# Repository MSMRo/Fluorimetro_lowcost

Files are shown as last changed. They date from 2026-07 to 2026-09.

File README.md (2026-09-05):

# Fluorímetro Low Cost

Proyecto de desarrollo de un fluorímetro de bajo costo basado en Arduino. Este proyecto integra circuitos de transmisión, recepción y diseño 3D para crear un sistema completo de medición de fluorescencia.

## 📋 Descripción General

Un fluorímetro es un instrumento que mide la fluorescencia de sustancias. Este proyecto implementa una solución accesible utilizando:
- **Plataforma de control**: Arduino Mega
- **Sensor espectral**: AS7341 (multiespectrométrico)
- **Excitación**: LED controlado con DAC Delta-Sigma
- **Visualización**: Pantalla OLED Nokia 5110

## 📁 Estructura del Proyecto

```
Fluorimetro_lowcost/
├── 1_Circuito/              # Diseños de circuitos
│   ├── 1_Transmisor/        # Circuito transmisor (LED de excitación)
│   │   └── 1_TESTS/         # Pruebas y códigos
│   │       ├── 1_CORRIENTE_DELTA_SIGMA/  # Pruebas DAC Delta-Sigma
│   │       ├── 2_DAC_LED_UNO_R4/         # Pruebas para UNO R4
│   │       └── 3_TEST_KICAD/             # Diseño del shield en KiCAD
│   └── 2_Receptor/          # Circuito receptor (sensor AS7341)
│       └── 1_TEST_AS7341/   # Códigos y pruebas del sensor
├── 3_Diseño3D/              # Modelos 3D (FreeCAD)
│   ├── 1_CASE_MEGA/         # Case para Arduino Mega v1
│   └── 2_CASE_MEGA_CUBO/    # Case con cubo integrado v2
└── README.md
```

## 🔧 Circuitos

### 1. Transmisor (1_Circuito/1_Transmisor/)

Responsable de generar la luz de excitación para estimular la fluorescencia de la muestra.

**Características principales:**
- Controlador de LED con DAC Delta-Sigma para modulación de intensidad
- Múltiples versiones testeadas:
  - **Delta-Sigma para Arduino Mega**: Conversión analógica de alta resolución
  - **DAC LED UNO R4**: Variante para Arduino UNO R4
  - **Shield KiCAD**: Diseño de PCB personalizado con biblioteca 3D

**Pruebas incluidas:**
- `dac_delta_sigma_MEGA_R3_v1.ino`: Firmware para Mega
- `dac_delta_sigma_UNO_R3_v1.ino`: Firmware para UNO
- Simulaciones en SPICE para validación

### 2. Receptor (1_Circuito/2_Receptor/)

Captura el espectro de luz emitido por la muestra fluorescente.

**Sensor AS7341 (ams OSRAM):**
- **10 canales de medición**:
  - 8 canales visibles (F1-F8): 415 nm a 680 nm
  - 1 canal NIR (infrarrojo cercano): 910 nm
  - 1 canal Clear (luz blanca sin filtro)
- **Comunicación**: I2C (SDA/SCL)
- **Características**:
  - Conversores ADC independientes para cada canal
  - Ganancia ajustable (hasta 512x+)
  - Tiempo de integración configurable
  - Ideal para detectar señales tenues sin saturación

**Códigos de prueba:**
- `firmware2.ino`: Firmware principal funcional (control de LED + lectura de máximos)
- `long_onda_oled.ino`: Visualización en pantalla OLED Nokia
- `maximo_4long_onda.ino`: Muestra los 4 canales con máxima intensidad
- Librería: **Adafruit AS7341** (IDE Arduino)

**Visualización:**
- Pantalla OLED Nokia 5110 con comunicación SPI
- Display de 84x48 píxeles con limitación visual (se muestran 4 máximos canales)

## 🎨 Diseño 3D

Modelos CAD para encapsulamiento y estructura mecánica del dispositivo.

### CASE_MEGA (1_CASE_MEGA/)
- **Prototipo v1** del case para Arduino Mega
- Adaptación de diseño de terceros para incluir compartimento de cuveta
- Software: FreeCAD v1.1.1
- Basado en: [Arduino Mega 2560 Case](https://www.printables.com/model/523194-arduino-mega-2560-case/files)

### CASE_MEGA_CUBO (2_CASE_MEGA_CUBO/)
- **Prototipo v2** con integración del cubo de excitación
- Combina case del Arduino Mega + estructura para fluoróforo
- Diseño consolidado en un solo componente

## 🛠️ Herramientas y Tecnologías

| Componente | Herramienta/Tecnología |
|---|---|
| Placa de control | Arduino Mega 2560 |
| Sensor | AS7341 (ams OSRAM) |
| Prototipado electrónico | KiCAD |
| Modelado 3D | FreeCAD v1.1.1 |
| Simulación de circuitos | SPICE |
| Programación | Arduino IDE, C/C++ |

## 📚 Bibliotecas Requeridas

- **Adafruit AS7341**: Control del sensor espectral
- **Adafruit GFX**: Gráficos para pantallas
- **Adafruit PCD8544**: Control de pantalla Nokia 5110
- **Wire**: Protocolo I2C
- **SPI**: Protocolo SPI

## 🚀 Estado del Proyecto

- ✅ Sensor AS7341 funcionando correctamente
- ✅ Control de LED con DAC Delta-Sigma
- ✅ Visualización en OLED Nokia
- ✅ Diseños 3D de prototipos
- 🔄 Optimización y validación del sistema completo

## 📝 Notas

- El firmware2 es la versión principal estable
- Se han testeado múltiples configuraciones de hardware
- Los diseños 3D están listos para impresión 3D
- Documentación con imágenes disponible en cada subdirectorio

---

*Proyecto en desarrollo - Low Cost Fluorimeter*

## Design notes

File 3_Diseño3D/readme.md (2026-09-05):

## Protipo de case para arduino mega 1
### Nombre: CASE_MEGA
Se uso un ```stl``` de un arduino mega y luego se adaptó para tener la capacidad de adicionar la parte del cuveta para colocar el fluoroforo.

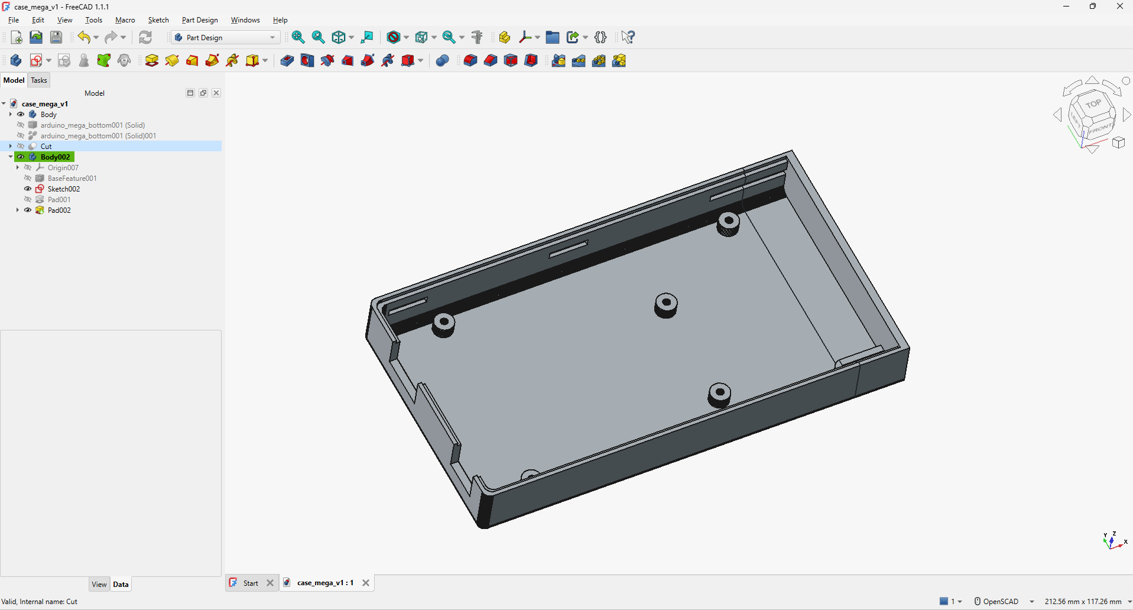
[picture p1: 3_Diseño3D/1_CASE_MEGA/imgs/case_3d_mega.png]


EL diseño se adaptó de este proyecto [LINK_PROYECTO](https://www.printables.com/model/523194-arduino-mega-2560-case/files)

El software usado fue:
- Freecad v1.1.1

## Protipo de case para arduino mega 2
### Nombre: CASE_MEGA_CUBO
Se realizó otro diseño 3D del prototipo, en esta ocasión se juntaron el case del arduino mega y el cubo para realizar la excitación del fluoroforo.
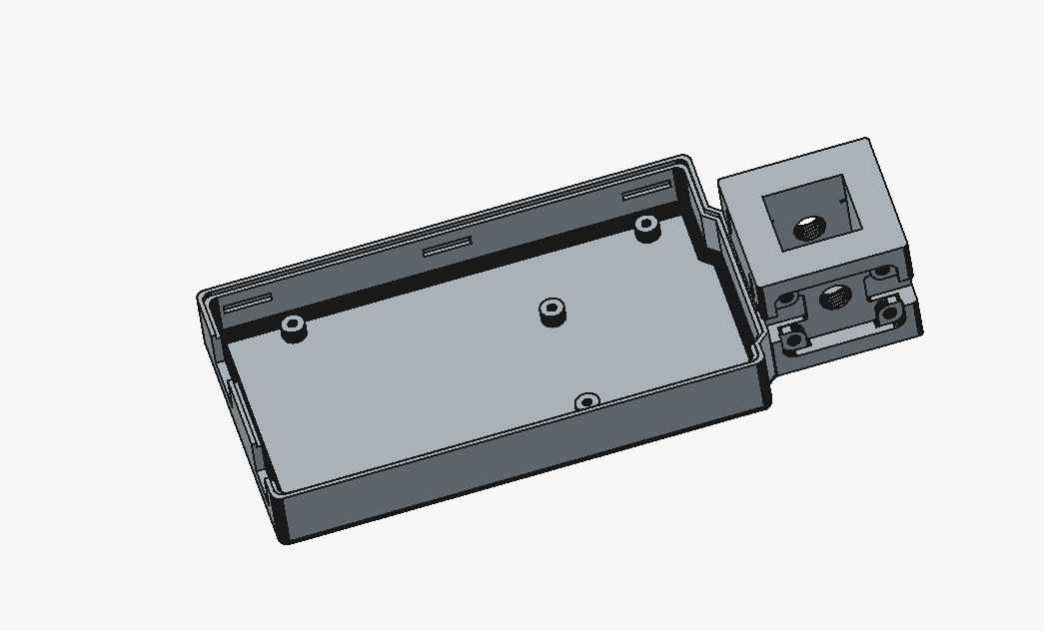
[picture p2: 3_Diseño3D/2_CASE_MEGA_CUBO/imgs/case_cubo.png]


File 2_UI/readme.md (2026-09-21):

# Arquitectura de software de `UI_Miguel`

Esta sección describe la arquitectura del contenido de [`UI_Miguel/`](UI_Miguel/) con el modelo C4. La ruta principal es la demostración con Arduino Mega 2560 y AS7341; la integración IO Rodeo con PyBadge y TSL2591 se conserva como una ruta histórica compatible.

## Nivel 1: contexto del sistema

El sistema permite operar el fluorímetro, observar las lecturas espectrales y conservar resultados experimentales. La persona operadora interactúa con la GUI desde un computador; el hardware realiza la adquisición y aplica los parámetros recibidos.

```mermaid
C4Context
	title Contexto del sistema: UI_Miguel

	Person(operator, "Operador/a", "Configura la adquisición, observa las lecturas y registra experimentos")
	System(fluorimeter, "Sistema de software del fluorímetro", "Controla la adquisición, procesa las mediciones y guarda la evidencia experimental")
	System_Ext(mega, "Arduino Mega + AS7341", "Adquiere diez canales y controla el LED por PWM")
	System_Ext(nokia, "Pantalla Nokia 5110", "Muestra el estado y los canales medidos")
	System_Ext(io_rodeo, "IO Rodeo + PyBadge", "Ruta histórica con TSL2591 y firmware adaptado")
	System_Ext(filesystem, "Sistema de archivos", "Almacena sesiones JSON y telemetría CSV")

	Rel(operator, fluorimeter, "Opera mediante")
	Rel(fluorimeter, mega, "Configura y recibe telemetría por USB serial")
	Rel(mega, nokia, "Actualiza la pantalla local")
	Rel(fluorimeter, io_rodeo, "Puede operar la ruta histórica por USB CDC")
	Rel(fluorimeter, filesystem, "Guarda sesiones y exportaciones")
```

## Nivel 2: contenedores

En C4, los contenedores son unidades desplegables o ejecutables. En la ruta Mega, la aplicación Python se ejecuta en el computador y el firmware C++ se carga en el microcontrolador.

```mermaid
C4Container
	title Contenedores: GUI Mega y firmware

	Person(operator, "Operador/a", "Usuario del instrumento")
	System_Boundary(system, "Sistema del fluorímetro") {
		Container(gui, "GUI de escritorio", "Python + PyQt", "Interfaz, adquisición, análisis, experimentos, gráficos y exportaciones")
		ContainerDb(sessions, "Sesiones y registros", "JSON + CSV", "Experimentos, telemetría y resultados recuperables")
		Container(serial, "Enlace USB serial", "JSON Lines, 115200 baudios", "Transporte de comandos y telemetría")
		Container(firmware, "Firmware Mega", "C++ / Arduino", "Lectura AS7341, pantalla Nokia, configuración y PWM D11")
	}
	System_Ext(sensor, "AS7341", "Sensor multicanal")
	System_Ext(display, "Nokia 5110", "Pantalla local")

	Rel(operator, gui, "Configura y observa")
	Rel(gui, serial, "Envía comandos y recibe líneas JSON")
	Rel(serial, firmware, "Transporta el protocolo")
	Rel(firmware, sensor, "Lee F1-F8, NIR y Clear por I2C")
	Rel(firmware, display, "Renderiza dos páginas de cinco valores")
	Rel(gui, sessions, "Lee y escribe sesiones, CSV y resultados")
```

La ruta histórica utiliza los contenedores `IO_Rodeo_TSL2591_GUI/v1.0` y `Firmware/IO_Rodeo_PyBadge/v2.0_tsl2591_gui`. La GUI recibe por USB CDC los valores que el PyBadge usa para su pantalla y permite observarlos, graficarlos y exportarlos; no sustituye la adquisición del firmware.

## Nivel 3: componentes de la GUI Mega

Los componentes se corresponden con los módulos de [`Software/Arduino_Mega_AS7341_GUI/v1.0/desktop_gui/`](UI_Miguel/Software/Arduino_Mega_AS7341_GUI/v1.0/desktop_gui/).

```mermaid
C4Component
	title Componentes: GUI Arduino Mega + AS7341

	Container_Boundary(gui, "GUI de escritorio") {
		Component(window, "Ventana principal", "main_window.py", "Coordina controles, estado y vistas")
		Component(protocol, "Protocolo", "protocol.py", "Codifica comandos y valida mensajes JSON Lines")
		Component(client, "Cliente serial", "serial_client.py", "Gestiona el puerto USB y la comunicación")
		Component(acquisition, "Adquisición", "acquisition.py", "Recibe, valida y distribuye frames de medición")
		Component(plot, "Vista espectral", "spectral_plot.py", "Grafica F1-F8 y aplica escala fija o automática")
		Component(mirror, "Espejo Nokia", "display_mirror.py", "Representa el estado mostrado por la pantalla local")
		Component(experiments, "Experimentos", "experiments.py", "Gestiona blancos, señales, cocientes y calibración")
		Component(analysis, "Análisis y calidad", "fluorometry.py + results_quality.py", "Calcula intensidades, estadísticas, residuos y resultados")
		Component(storage, "Persistencia y exportación", "session_store.py + telemetry_writer.py + exporter.py", "Guarda JSON, CSV y sesiones recuperables")
	}
	Container_Ext(firmware, "Firmware Mega", "C++ / Arduino", "Telemetría y control del instrumento")

	Rel(window, acquisition, "Consume estado y mediciones")
	Rel(window, plot, "Actualiza la vista")
	Rel(window, mirror, "Actualiza el espejo")
	Rel(window, experiments, "Inicia y valida capturas")
	Rel(window, analysis, "Muestra resultados")
	Rel(protocol, client, "Define mensajes")
	Rel(client, firmware, "Envía comandos y recibe JSON Lines")
	Rel(client, acquisition, "Entrega telemetría")
	Rel(acquisition, storage, "Registra mediciones")
	Rel(experiments, analysis, "Entrega capturas y configuración")
	Rel(analysis, storage, "Persiste resultados y derivados")
```

## Nivel 4: código y contratos principales

El nivel de código se resume en los contratos que conectan los componentes. No se detallan todas las funciones internas para evitar convertir el README en una copia del código fuente.

| Elemento | Responsabilidad o contrato |
| --- | --- |
| `mega_as7341_multichannel.ino` + `firmware.cpp` | Inicializa AS7341 y Nokia, lee diez canales raw, aplica ganancia, integración y PWM de D11, y emite estado/telemetría JSON Lines. |
| `protocol.py` | Mantiene el formato de comandos como `set_gain`, `set_integration`, `set_pwm` y las respuestas del firmware. |
| `serial_client.py` | Abre el puerto USB a 115200 baudios y separa las líneas recibidas del dispositivo. |
| `acquisition.py` | Convierte la telemetría en frames de adquisición y conserva la información de saturación `OVFL`. |
| `experiments.py` | Modela capturas de blanco, señal, A/B, réplicas y compatibilidad de configuración. |
| `fluorometry.py` + `results_quality.py` | Calculan intensidades corregidas, cocientes, estadísticas, residuos y controles de calidad sin inventar datos ausentes. |
| `session_store.py` + `telemetry_writer.py` + `exporter.py` | Persisten la sesión en JSON, la telemetría en CSV y las tablas derivadas para análisis posterior. |

### Flujo de datos principal

1. El operador cambia ganancia, integración o PWM en la GUI.
2. `protocol.py` serializa el comando y `serial_client.py` lo envía al Mega.
3. El firmware configura el AS7341, adquiere F1-F8, NIR y Clear, actualiza la Nokia y devuelve JSON Lines.
4. `acquisition.py` valida el frame; la gráfica y el espejo muestran el estado actual.
5. `experiments.py` captura la medición bajo una configuración identificable.
6. `fluorometry.py` y `results_quality.py` calculan los derivados; la capa de persistencia guarda JSON y CSV.

### Límites de la arquitectura

- Las pruebas host del firmware y las pruebas Qt validan el contrato de software, pero no reemplazan la validación óptica con estándares y el montaje real.
- Las lecturas del AS7341 se conservan como cuentas ADC raw; `OVFL` representa saturación digital.
- La carpeta `reference_upstream` del firmware IO Rodeo es material de referencia y no forma parte del flujo principal de desarrollo.

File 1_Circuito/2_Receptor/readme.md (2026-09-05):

# RECEPTOR

A nivel del receptor estamos trabajando con el AS7341
El AS7341 es un sensor espectral multicanal de alta precisión desarrollado por ams OSRAM, ideal para aplicaciones de análisis de color y espectroscopia como tu fluorímetro:
* Canales de Medición: Cuenta con un total de 10 canales:
    * 8 canales visibles (F1 a F8) con filtros ópticos integrados de fábrica, que cubren desde el violeta hasta el rojo lejano (de $415\text{ nm}$ a $680\text{ nm}$).
    * 1 canal NIR (Infrarrojo Cercano) sintonizado a $910\text{ nm}$.
    * 1 canal Clear que mide la luz blanca total sin filtrar.

* Comunicación: Se conecta mediante el protocolo I2C, lo que facilita su integración directa con microcontroladores como el Arduino Mega utilizando solo dos cables de datos (SDA y SCL).
* Conversión Analógica-Digital (ADC): Incorpora conversores ADC independientes para procesar las lecturas de los fotodiodos de manera simultánea, entregando datos digitales de alta resolución directamente al microcontrolador.
* Ganancia y Tiempo de Integración Ajustables: Permite configurar parámetros de ganancia interna (hasta 512x o más) y tiempos de integración mediante software, lo cual es fundamental en fluorometría para detectar señales de luz extremadamente tenues sin saturar el sensor.


# Pruebas
La libreria para usar el AS7341 es ```Adafruit AS7341``` en el ide de arduino.

## 1_TEST_AS7341

### firmware2
Actualmente el firmware2 es el código funcional. Permite controlar el brillo del LED y la muestra de los maximos valores de los canales del sensor.


### long_onda_oled
Se desarrollo un código para mostrar los canales y su intensidad.

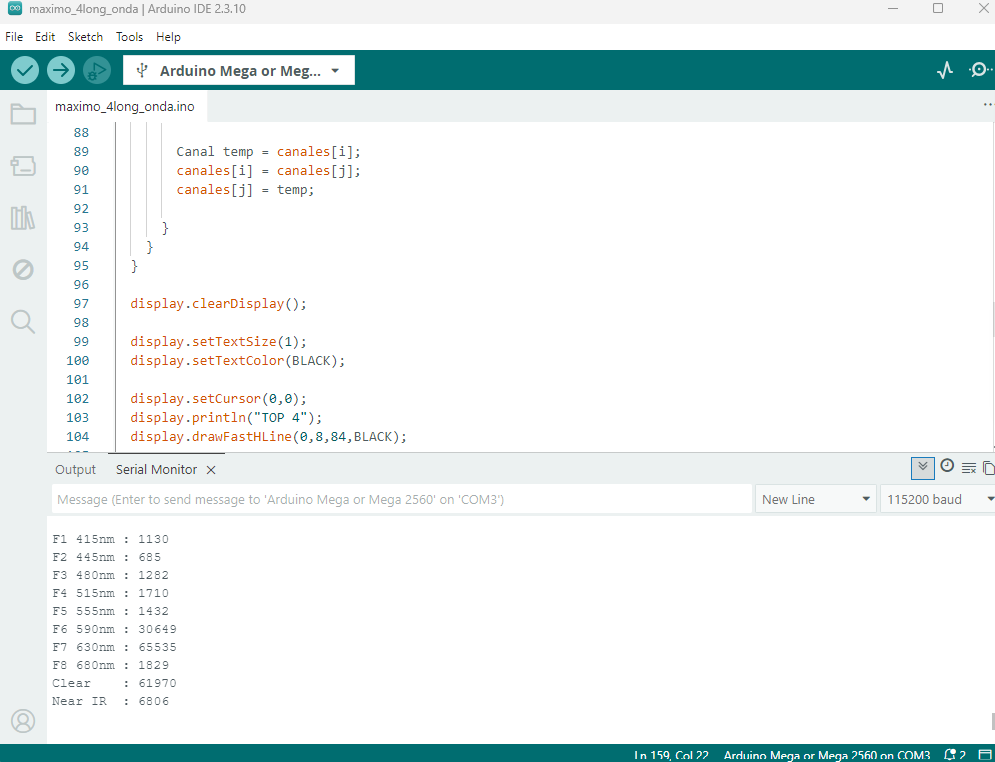
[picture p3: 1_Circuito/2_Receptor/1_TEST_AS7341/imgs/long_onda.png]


A nivel de implementación se adaptó el código para poder visualizarse en el OLED NOKIA. Se muestra solamente los 4 máximos valores, ya que el NOKIA solo tiene limitado visivilidad.

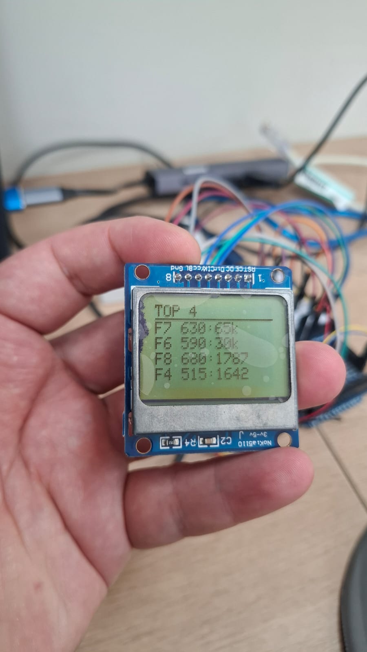
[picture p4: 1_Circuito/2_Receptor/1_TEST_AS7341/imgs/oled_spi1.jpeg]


## Código

```c
#include <Wire.h>
#include <SPI.h>
#include <Adafruit_GFX.h>
#include <Adafruit_PCD8544.h>
#include <Adafruit_AS7341.h>

//================== Pantalla Nokia 5110 ==================

// Pines de la pantalla
const int pin_DC  = 5;
const int pin_CE  = 4;
const int pin_RST = 3;

// Software SPI: CLK, DIN, DC, CE, RST
Adafruit_PCD8544 display = Adafruit_PCD8544(52, 51, pin_DC, pin_CE, pin_RST);

//================== Sensor AS7341 ==================

Adafruit_AS7341 as7341;

// Estructura para almacenar nombre y valor de cada canal
struct Canal {
  const char* nombre;
  uint16_t valor;
};

void setup() {

  Serial.begin(115200);

  // Inicializar pantalla
  display.begin();
  display.setContrast(55);
  display.setRotation(2);
  display.clearDisplay();
  display.display();

  // Inicializar sensor
  if (!as7341.begin()) {

    display.clearDisplay();
    display.setCursor(0,0);
    display.println("ERROR");
    display.println("AS7341");
    display.println("No detectado");
    display.display();

    while (1);
  }

  // Configuración para alta sensibilidad
  as7341.setATIME(100);
  as7341.setASTEP(999);
  as7341.setGain(AS7341_GAIN_256X);
}

void loop() {

  if (!as7341.readAllChannels()) {
    Serial.println("Error leyendo AS7341");
    delay(500);
    return;
  }

  actualizarPantalla();

  delay(200);
}

void actualizarPantalla() {

  Canal canales[8] = {
    {"F1 415", as7341.getChannel(AS7341_CHANNEL_415nm_F1)},
    {"F2 445", as7341.getChannel(AS7341_CHANNEL_445nm_F2)},
    {"F3 480", as7341.getChannel(AS7341_CHANNEL_480nm_F3)},
    {"F4 515", as7341.getChannel(AS7341_CHANNEL_515nm_F4)},
    {"F5 555", as7341.getChannel(AS7341_CHANNEL_555nm_F5)},
    {"F6 590", as7341.getChannel(AS7341_CHANNEL_590nm_F6)},
    {"F7 630", as7341.getChannel(AS7341_CHANNEL_630nm_F7)},
    {"F8 680", as7341.getChannel(AS7341_CHANNEL_680nm_F8)}
  };

  // Ordenar de mayor a menor
  for (int i = 0; i < 7; i++) {
    for (int j = i + 1; j < 8; j++) {

      if (canales[j].valor > canales[i].valor) {

        Canal temp = canales[i];
        canales[i] = canales[j];
        canales[j] = temp;

      }
    }
  }

  display.clearDisplay();

  display.setTextSize(1);
  display.setTextColor(BLACK);

  display.setCursor(0,0);
  display.println("TOP 4");
  display.drawFastHLine(0,8,84,BLACK);

  for (int i = 0; i < 4; i++) {

    display.setCursor(0,10 + i*9);

    display.print(canales[i].nombre);
    display.print(":");

    uint16_t v = canales[i].valor;

    // Mostrar valores grandes en miles para que entren en la pantalla
    if (v >= 10000) {
      display.print(v / 1000);
      display.print("k");
    } else {
      display.print(v);
    }
  }

  display.display();

  // También imprimir por Serial
  /*
  Serial.println("----- TOP 4 -----");
  for (int i = 0; i < 4; i++) {
    Serial.print(canales[i].nombre);
    Serial.print(": ");
    Serial.println(canales[i].valor);
  }
  Serial.println();
  */
    Serial.print("F1 415nm : ");
  Serial.println(as7341.getChannel(AS7341_CHANNEL_415nm_F1));
  Serial.print("F2 445nm : ");
  Serial.println(as7341.getChannel(AS7341_CHANNEL_445nm_F2));
  Serial.print("F3 480nm : ");
  Serial.println(as7341.getChannel(AS7341_CHANNEL_480nm_F3));
  Serial.print("F4 515nm : ");
  Serial.println(as7341.getChannel(AS7341_CHANNEL_515nm_F4));
  Serial.print("F5 555nm : ");
  Serial.println(as7341.getChannel(AS7341_CHANNEL_555nm_F5));
  Serial.print("F6 590nm : ");
  Serial.println(as7341.getChannel(AS7341_CHANNEL_590nm_F6));
  Serial.print("F7 630nm : ");
  Serial.println(as7341.getChannel(AS7341_CHANNEL_630nm_F7));
  Serial.print("F8 680nm : ");
  Serial.println(as7341.getChannel(AS7341_CHANNEL_680nm_F8));

  Serial.print("Clear    : ");
  Serial.println(as7341.getChannel(AS7341_CHANNEL_CLEAR));

  Serial.print("Near IR  : ");
  Serial.println(as7341.getChannel(AS7341_CHANNEL_NIR));

  Serial.println("");
}
```

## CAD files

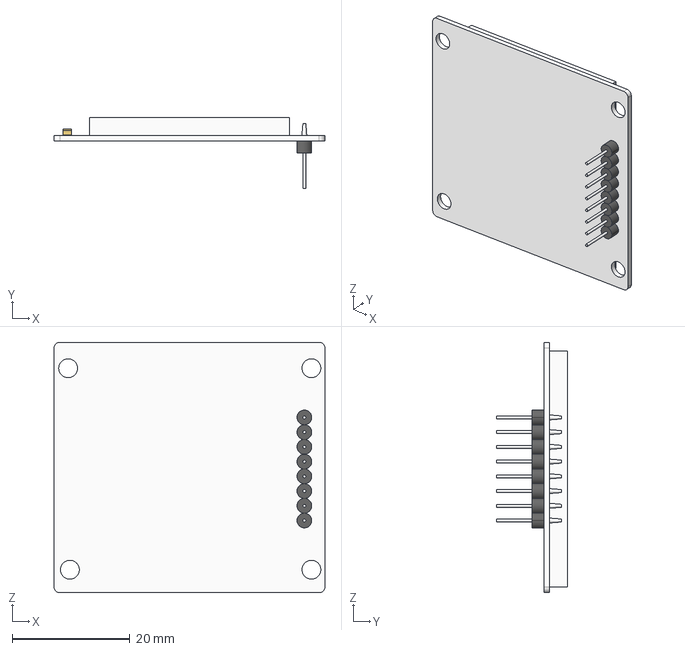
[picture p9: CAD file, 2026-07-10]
1_Circuito/1_Transmisor/1_TESTS/3_TEST_KICAD/shield_arduino/Librerias_step/nokia-5110-lcd-graphic-84x48-pixel-arduiono-compatible-blue-board-1.snapshot.2/Nokia LCD.stp
46.0 x 12.0 x 42.5 mm

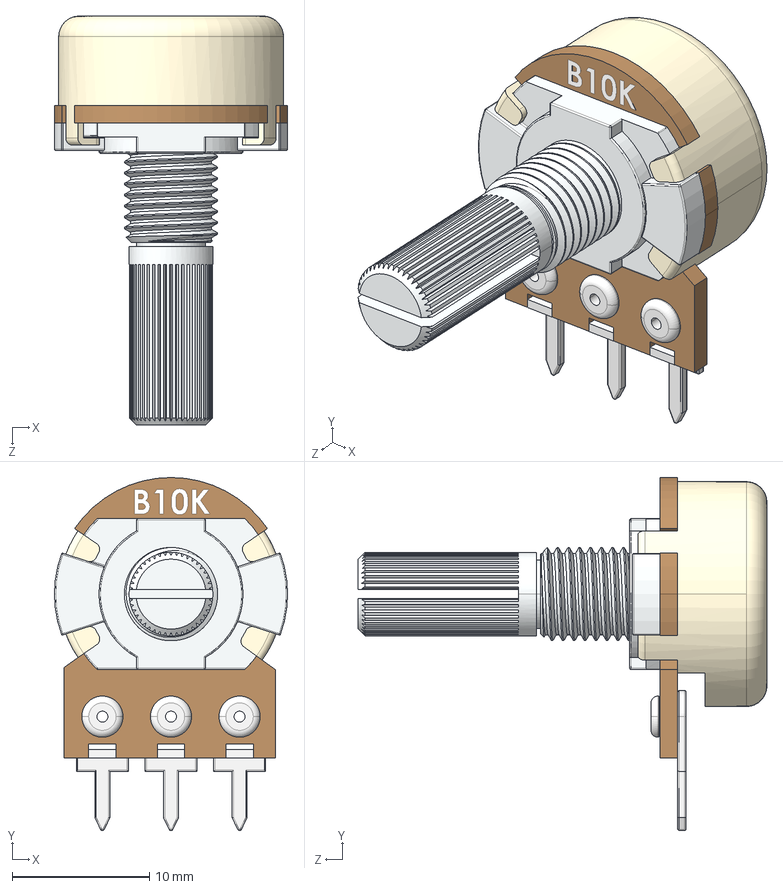
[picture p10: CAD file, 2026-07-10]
1_Circuito/1_Transmisor/1_TESTS/3_TEST_KICAD/shield_arduino/Librerias_step/potenciometro-circuito-impresso-10k-1.snapshot.1/Potenciometro PCI 10K/Potenciometro PCI 10K.STEP
17.0 x 25.7 x 29.8 mm
Peça1^Potenciometro
Peça2^Potenciometro
Peça3^Potenciometro
Peça5^Potenciometro
Peça6^Potenciometro x 3

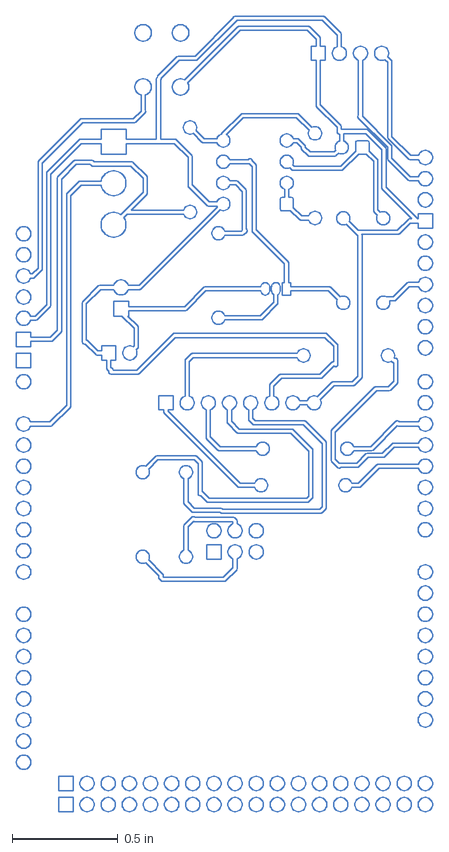
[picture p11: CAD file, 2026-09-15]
1_Circuito/1_Transmisor/1_TESTS/3_TEST_KICAD/shield_arduino/shield_arduino-B_Cu.dxf
1.97 x 3.76 in

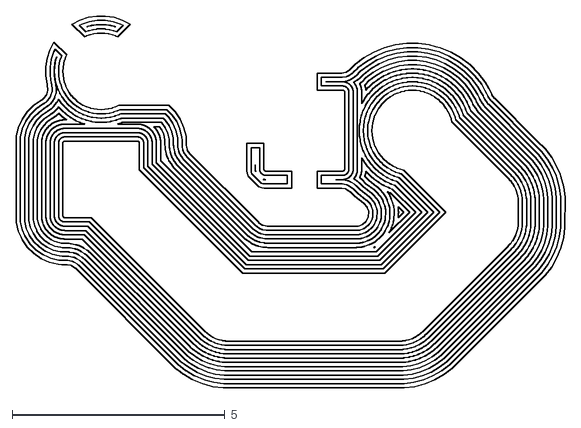
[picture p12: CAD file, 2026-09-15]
1_Circuito/1_Transmisor/2_CIRCUITS/3_MODULO_LED/LED_EXCITATOR/LED_EXCITATOR-B_Cu.gbr_iso_combined_4.DXF
12.9 x 8.74

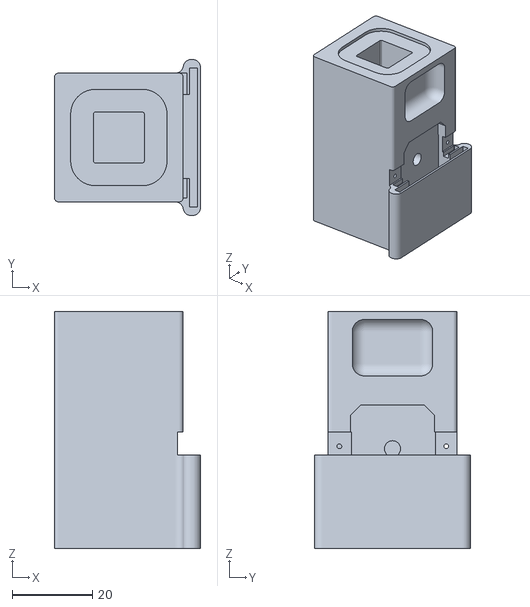
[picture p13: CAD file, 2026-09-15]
2_UI/UI_Miguel/Hardware/3D_Models/Carcasa_v1/carcasa_final.stl
36.3 x 38.8 x 58.9

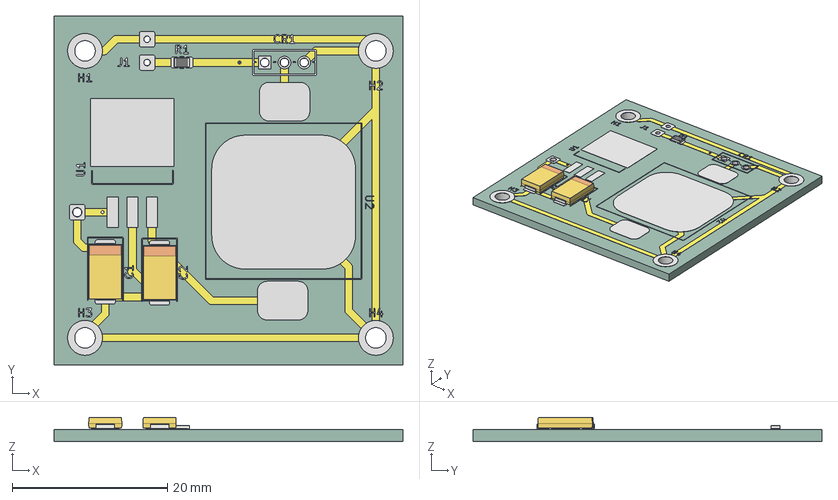
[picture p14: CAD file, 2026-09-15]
2_UI/UI_Miguel/Hardware/Electronics/Excitation/Excite_V1/Excite_V1.step
45.0 x 45.0 x 3.13 mm
CP_EIA-7343-15_Kemet-W x 2
R_0805_2012Metric
Excite_V1_copper
Excite_V1_pad
Excite_V1_silkscreen
Excite_V1_PCB

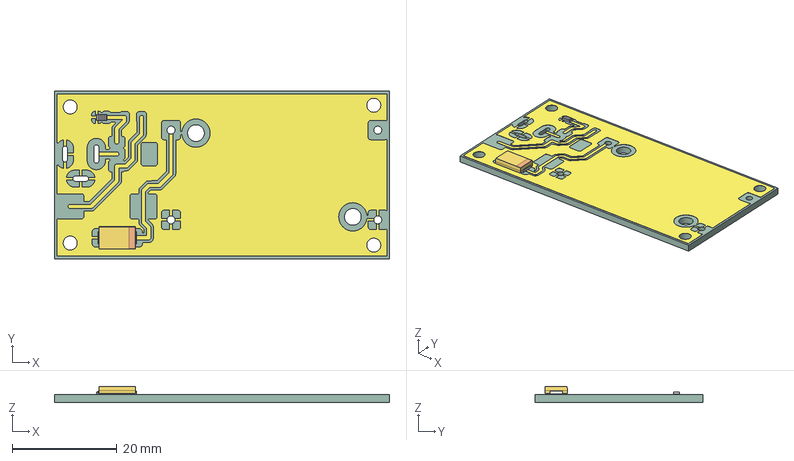
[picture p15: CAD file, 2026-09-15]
2_UI/UI_Miguel/Hardware/Electronics/Power/Energy/Energia .step
64.0 x 32.0 x 3.09 mm
R_0805_2012Metric
CP_EIA-7343-15_Kemet-W
Untitled_copper
Untitled_PCB

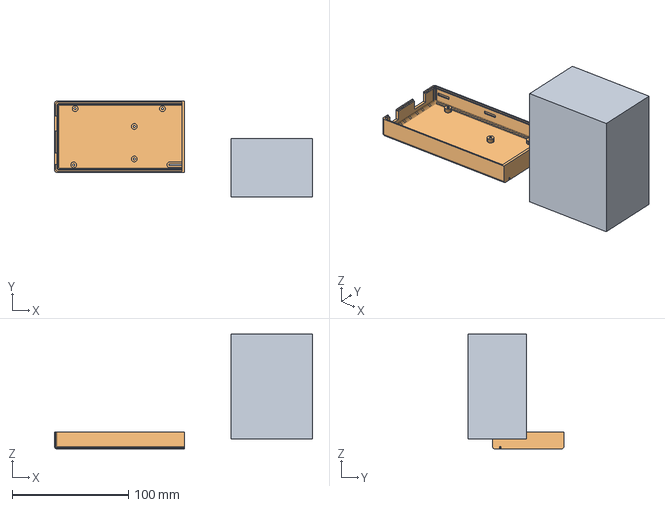
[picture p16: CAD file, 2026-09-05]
3_Diseño3D/1_CASE_MEGA/case_mega_v1.FCStd
221.5 x 82.3 x 98.6 mm

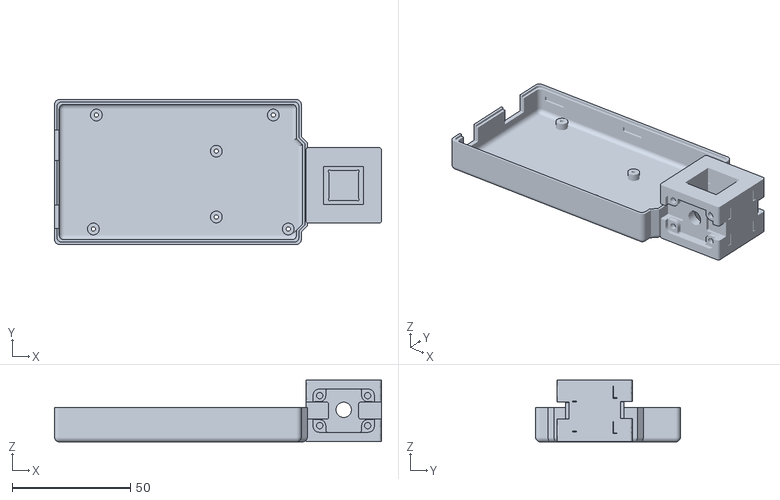
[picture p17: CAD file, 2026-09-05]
3_Diseño3D/2_CASE_MEGA_CUBO/case_cubo-Fusion.stl
138.5 x 61.3 x 26.2

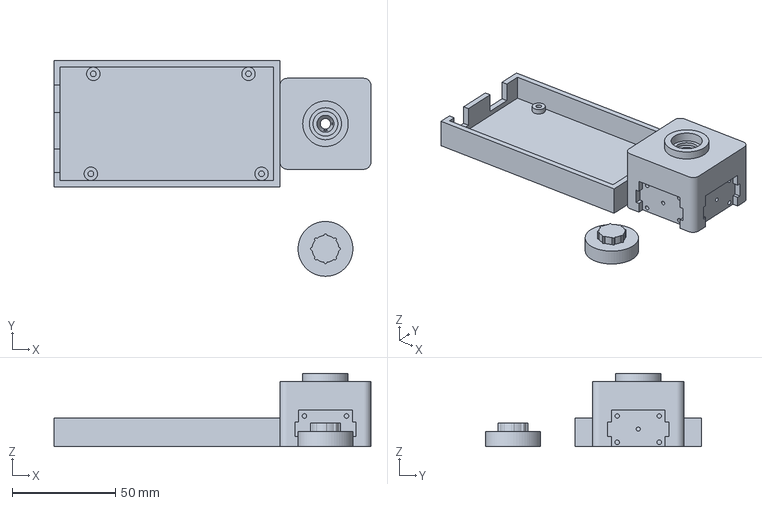
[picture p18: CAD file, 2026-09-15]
3_Diseño3D/3_PRUEBAS_VARIOS/3D/soporte_fluorimetro.FCStd
153.2 x 104.2 x 35.5 mm

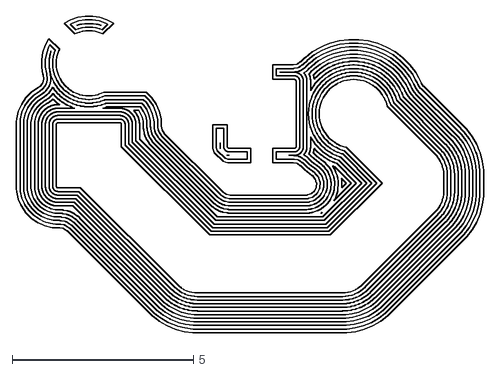
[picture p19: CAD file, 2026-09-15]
1_Circuito/1_Transmisor/2_CIRCUITS/3_MODULO_LED/LED_EXCITATOR/LED_EXCITATOR-B_Cu.gbr_iso_combined_3.DXF
12.9 x 8.74

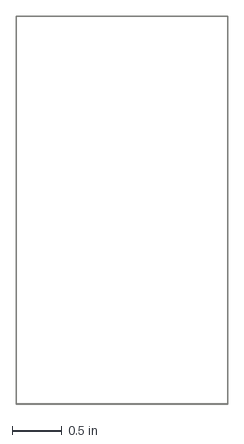
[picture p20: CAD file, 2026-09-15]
1_Circuito/1_Transmisor/1_TESTS/3_TEST_KICAD/shield_arduino/shield_arduino-Edge_Cuts_1.dxf
2.12 x 3.89 in

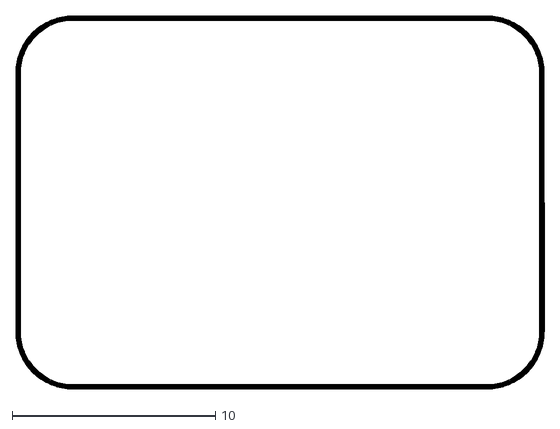
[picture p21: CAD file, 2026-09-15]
1_Circuito/1_Transmisor/2_CIRCUITS/3_MODULO_LED/LED_EXCITATOR/LED_EXCITATOR-Edge_Cuts.gbr_iso_combined_4.DXF
26.0 x 18.3

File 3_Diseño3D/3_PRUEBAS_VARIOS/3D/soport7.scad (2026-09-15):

/* =================================================================
   Fluorímetro Integrado + Case Arduino Mega 2560 R3 + Tapa Óptica
   (Versión Calibrada 1:1 a Microtubo Real de 0.5 mL)
   - Altura del bloque óptico reducida a 31.5 mm
   - Cuello superior compacto (d=15 mm, h=3 mm)
   - Cavidad interior pasante con apoyo a ras para el labio del tubo
   - Sin colisión de pernos en 90° (bloque 44 x 44 mm)
   ================================================================= */

$fn = 60;

// =================================================================
// 1. CASE ARDUINO MEGA 2560 R3 (CALIBRADO)
// =================================================================
mega_pcb_w       = 101.6; 
mega_pcb_d       = 53.34; 
mega_wall        = 3.0;   
mega_floor       = 2.0;   
standoff_h       = 2.5;   

case_outer_h     = 14.0;  
case_inner_h     = case_outer_h - mega_floor; 

standoff_od      = 6.5;   
standoff_id      = 2.8;   // Para tornillo M3

clearance        = 0.8; 
case_inner_x     = mega_pcb_w + clearance * 2;
case_inner_y     = mega_pcb_d + clearance * 2;
case_outer_x     = case_inner_x + mega_wall * 2;
case_outer_y     = case_inner_y + mega_wall * 2;

mega_holes = [
    [14.0, 2.5],
    [15.2, 50.8],
    [90.2, 50.8],
    [96.5, 2.5]
];

usb_w            = 13.5;  
usb_y_pos        = 32.0;  
jack_w           = 11.5;  
jack_y_pos       = 3.0;   

// =================================================================
// 2. BLOQUE ÓPTICO Y MICROTUBO 0.5 mL (MEDIDAS REALES)
// =================================================================
block_size       = 44.0;  // 44 x 44 mm (evita cruce de tornillos)
block_height     = 31.5;  // Altura calibrada a la longitud del tubo
corner_radius    = 3.5;

// Dimensiones reales del microtubo 0.5 mL (con holgura)
tube_body_dia     = 8.2;  // Diámetro del cuerpo
cone_end_dia      = 4.6;  // Diámetro en la punta del cono
rim_dia           = 13.0; // Rebaje para el labio/pestaña del tubo
rim_depth         = 1.8;  // Espesor real del borde del tubo
bottom_window_dia = 5.0;  // Diámetro ventana de inspección inferior

// Cuello superior compacto
collar_h          = 3.0;  // Altura del cuello (mm)
collar_od         = 15.4; // Diámetro exterior ajustado al borde del tubo
collar_id         = 12.6; // Diámetro interior que permite paso de la cabeza

// Eje óptico alineado con el líquido fluorescente en el cono
optical_z         = 8.5;  
pinhole_dia       = 2.0;

tube_pos_x        = block_size / 2; // 22.0 mm
tube_pos_y        = block_size / 2; // 22.0 mm

// Placas AS7341 y Placa LED
pcb_w             = 26.0;
pcb_h             = 18.4;
pocket_depth      = 3.0;
hole_pitch_w      = 20.32;
hole_pitch_h      = 12.70;
mount_screw_dia   = 2.2;
mount_screw_len   = 4.5;

fluor_pos_x       = case_outer_x;
fluor_pos_y       = (case_outer_y - block_size) / 2;

// Parámetros de la tapa compacta
cap_clearance     = 0.25;  
cap_wall          = 1.6;   
cap_top_thick     = 2.0;   
knob_h            = 3.5;   
knob_dia          = 10.0;  

// =================================================================
// RENDERIZADO
// =================================================================
fluorimetro_completo();

// Tapa compacta lista para impresión
translate([fluor_pos_x + block_size/2, -collar_od - 6, 0])
    tapa_fluorimetro();


// =================================================================
// MÓDULOS
// =================================================================

module fluorimetro_completo() {
    difference() {
        // 1. Sólidos fusionados
        union() {
            case_arduino_mega();

            translate([fluor_pos_x, fluor_pos_y, 0])
                rounded_cube([block_size, block_size, block_height], corner_radius);

            // Cuello cilíndrico superior proporcionado
            translate([fluor_pos_x + tube_pos_x, fluor_pos_y + tube_pos_y, block_height])
                cylinder(h = collar_h, d = collar_od);
        }

        // 2. Cavidad interior continua del microtubo (pasante 100%)
        translate([fluor_pos_x + tube_pos_x, fluor_pos_y + tube_pos_y, 0])
            cavidad_tubo_calibrada();

        // 3. Montura Sensor AS7341 (Cara Y)
        translate([fluor_pos_x, fluor_pos_y, 0])
            cavidad_montura();

        // 4. Montura Placa LED a 90° (Cara X)
        translate([fluor_pos_x + block_size, fluor_pos_y, 0])
            rotate([0, 0, 90])
                cavidad_montura();
    }
}

// Perfil de revolución del microtubo 0.5 mL (continuo, sin tabiques ciegos)
module cavidad_tubo_calibrada() {
    z_bottom   = -1.0;                         // Traspasa suelo
    z_tip      = 2.0;                          // Apoyo de la punta
    z_cone_top = 15.5;                         // Fin del cono (13.5 mm de altura de cono)
    z_rim_seat = block_height - rim_depth;     // Asiento del labio del tubo (29.7 mm)
    z_top      = block_height + collar_h + 1.0;// Salida superior

    rotate_extrude() {
        polygon(points = [
            [0, z_bottom],
            [bottom_window_dia / 2, z_bottom],
            [bottom_window_dia / 2, z_tip],
            [tube_body_dia / 2, z_cone_top],
            [tube_body_dia / 2, z_rim_seat],
            [rim_dia / 2, z_rim_seat],
            [rim_dia / 2, block_height],
            [collar_id / 2, block_height],
            [collar_id / 2, z_top],
            [0, z_top]
        ]);
    }
}

// Cavidad de placa y orificios de fijación
module cavidad_montura() {
    // Canal óptico hacia el centro del líquido
    translate([tube_pos_x, -1, optical_z])
        rotate([-90, 0, 0])
            cylinder(h = tube_pos_y + 1, d = pinhole_dia);

    // Encastre de placa PCB
    translate([tube_pos_x - pcb_w/2, -0.1, optical_z - pcb_h/2])
        cube([pcb_w, pocket_depth + 0.1, pcb_h]);

    // Despeje para conectores STEMMA QT
    translate([tube_pos_x - (pcb_w + 3.5)/2, -0.1, optical_z - 3.5])
        cube([pcb_w + 3.5, pocket_depth + 0.1, 7.0]);

    // Despeje para regleta de pines soldados
    translate([tube_pos_x - 9.0, -0.1, optical_z - pcb_h/2 - 2.0])
        cube([18.0, pocket_depth + 0.1, 4.0]);

    // 4 Agujeros ciegos M2 / M2.5 independientes (sin colisión)
    for (dw = [-hole_pitch_w/2, hole_pitch_w/2]) {
        for (dh = [-hole_pitch_h/2, hole_pitch_h/2]) {
            translate([tube_pos_x + dw, pocket_depth - 0.1, optical_z + dh])
                rotate([-90, 0, 0])
                    cylinder(h = mount_screw_len, d = mount_screw_dia);
        }
    }
}

// Tapa Antifugas Proporcionada
module tapa_fluorimetro() {
    cap_inner_dia = collar_od + cap_clearance * 2;
    cap_outer_dia = cap_inner_dia + cap_wall * 2;
    cap_inner_h   = collar_h + 1.0; 
    cap_total_h   = cap_inner_h + cap_top_thick;

    union() {
        difference() {
            cylinder(h = cap_total_h, d = cap_outer_dia);

            translate([0, 0, -0.1])
                cylinder(h = cap_inner_h + 0.1, d = cap_inner_dia);

            translate([0, 0, -0.1])
                cylinder(h = 0.8, d1 = cap_inner_dia + 1.0, d2 = cap_inner_dia);
        }

        translate([0, 0, cap_total_h]) {
            cylinder(h = knob_h, d = knob_dia);
            for (a = [0 : 60 : 360]) {
                rotate([0, 0, a])
                    translate([knob_dia/2, 0, knob_h/2])
                        cylinder(h = knob_h, d = 1.2, center = true);
            }
        }
    }
}

// Case Arduino Mega 2560 Calibrado
module case_arduino_mega() {
    difference() {
        cube([case_outer_x, case_outer_y, case_outer_h]);

        translate([mega_wall, mega_wall, mega_floor])
            cube([case_inner_x, case_inner_y, case_inner_h + 1.0]);

        // Entrada USB Tipo B
        translate([-1, mega_wall + clearance + usb_y_pos, mega_floor + standoff_h])
            cube([mega_wall + 2, usb_w, case_outer_h]);

        // Entrada Jack DC
        translate([-1, mega_wall + clearance + jack_y_pos, mega_floor + standoff_h])
            cube([mega_wall + 2, jack_w, case_outer_h]);
    }

    for (h = mega_holes) {
        translate([mega_wall + clearance + h[0], mega_wall + clearance + h[1], mega_floor]) {
            difference() {
                cylinder(h = standoff_h, d = standoff_od);
                translate([0, 0, -0.5])
                    cylinder(h = standoff_h + 1.0, d = standoff_id);
            }
        }
    }
}

// Módulo auxiliar de redondeo
module rounded_cube(size, r) {
    x = size[0];
    y = size[1];
    z = size[2];
    hull() {
        translate([r, r, 0])         cylinder(h = z, r = r);
        translate([x - r, r, 0])     cylinder(h = z, r = r);
        translate([r, y - r, 0])     cylinder(h = z, r = r);
        translate([x - r, y - r, 0]) cylinder(h = z, r = r);
    }
}

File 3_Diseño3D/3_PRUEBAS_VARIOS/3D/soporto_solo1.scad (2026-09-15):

/* =================================================================
   Soporte Óptico para Fluorímetro (Microtubo 1.5 mL)
   - Estructura central, cuello y cavidad del tubo intactos
   - Cara del sensor AS7341 calibrada con desahogos pasantes para cables Qwiic
   - Cara del LED a 90° independiente
   - Tapa separada a distancia segura de impresión
   ================================================================= */

$fn = 60;

// --- Dimensiones del Bloque Base ---
block_w          = 42.0;  // Eje X
block_d          = 42.0;  // Eje Y
block_h          = 40.0;  // Altura calibrada al tubo de 1.5 mL
corner_r         = 3.5;

// Centro del microtubo
cx = block_w / 2; // 21.0 mm
cy = block_d / 2; // 21.0 mm

// --- Dimensiones del Microtubo de 1.5 mL ---
tube_body_dia     = 11.2; 
cone_tip_dia      = 4.8;  
cone_h            = 18.0; 
bottom_hole_dia   = 5.0;  
rim_seat_dia      = 15.0; 
rim_seat_depth    = 2.5;  

// Cuello superior cilíndrico
collar_h          = 4.5;
collar_od         = 22.0;
collar_id         = 15.5;

// --- Parámetros Ópticos ---
optical_z         = 10.5; // Altura del haz óptico
optic_hole_dia    = 3.6;  // Apertura central ampliada

// --- Montura Cara Sensor AS7341 (Cara Y=0) ---
as_pocket_w       = 27.5; // Ancho del receptáculo (holgura para PCB nominal 25.4 mm)
as_pocket_h       = 19.5; // Altura del receptáculo (holgura para PCB nominal 17.8 mm)
as_pocket_depth   = 3.2;  // Profundidad de asiento del PCB
hole_pitch_w      = 20.32;// Distancia entre tornillos M2/M2.5 horizontal (0.8")
hole_pitch_h      = 12.70;// Distancia entre tornillos vertical (0.5")
mount_screw_dia   = 2.2;
mount_screw_len   = 5.0;

// Desahogo amplio pasante para conectores y cables Qwiic / STEMMA QT
qwiic_slot_w      = 9.5;  // Altura de paso para conector JST-SH
qwiic_total_span  = 44.0; // Pasa de lado a lado cortando hacia el exterior
qwiic_depth       = 6.5;  // Profundidad para que el conector no choque la pared

// Desahogo frontal para componentes SMD y sensor central AS7341
smd_relief_w      = 11.0; 
smd_relief_h      = 8.5;
smd_relief_depth  = 1.5;  // Rebaje extra en el fondo

// --- Montura Cara LED (Cara X=0) ---
led_pocket_w      = 26.0;
led_pocket_h      = 18.4;
led_pocket_depth  = 3.0;

// --- Parámetro de Separación de la Tapa ---
distancia_tapa_x  = block_w + 25.0; // 67.0 mm (holgura cómoda sin interferencia)


// ==================== RENDERIZADO ====================
soporte_fluorimetro_1_5ml();

// Tapa hermética reubicada con mayor separación
translate([distancia_tapa_x, cy, 0])
    tapa_estanca();


// ==================== MÓDULOS ====================

module soporte_fluorimetro_1_5ml() {
    difference() {
        // 1. Bloque base sólido + cuello cilíndrico
        union() {
            rounded_cube([block_w, block_d, block_h], corner_r);

            translate([cx, cy, block_h])
                cylinder(h = collar_h, d = collar_od);
        }

        // 2. Vaciado interior continuo del microtubo de 1.5 mL
        translate([cx, cy, 0])
            cavidad_microtubo_1_5ml();

        // 3. Montura Cara Y=0: Sensor AS7341 con desahogos pasantes Qwiic
        cavidad_sensor_as7341();

        // 4. Montura Cara X=0: Placa LED estándar a 90°
        cavidad_modulo_led();
    }
}

// Cavidad de revolución 100% pasante para microtubo de 1.5 mL
module cavidad_microtubo_1_5ml() {
    z_floor    = -1.0;
    z_cone_end = 19.0;
    z_rim      = block_h - rim_seat_depth;
    z_exit     = block_h + collar_h + 1.0;

    rotate_extrude() {
        polygon(points = [
            [0, z_floor],
            [bottom_hole_dia / 2, z_floor],
            [bottom_hole_dia / 2, 2.0],
            [tube_body_dia / 2, z_cone_end],
            [tube_body_dia / 2, z_rim],
            [rim_seat_dia / 2, z_rim],
            [rim_seat_dia / 2, block_h],
            [collar_id / 2, block_h],
            [collar_id / 2, z_exit],
            [0, z_exit]
        ]);
    }
}

// Montura para Adafruit AS7341 (Cara Y=0)
module cavidad_sensor_as7341() {
    // Canal óptico hacia el microtubo
    translate([cx, -1.0, optical_z])
        rotate([-90, 0, 0])
            cylinder(h = cy + 1.0, d = optic_hole_dia);

    // Encastre principal para el PCB (con holgura de 27.5 mm)
    translate([cx - as_pocket_w/2, -0.1, optical_z - as_pocket_h/2])
        cube([as_pocket_w, as_pocket_depth + 0.1, as_pocket_h]);

    // Ranuras pasantes laterales continuas para los conectores y cables Qwiic
    translate([cx - qwiic_total_span/2, -0.1, optical_z - qwiic_slot_w/2])
        cube([qwiic_total_span, qwiic_depth, qwiic_slot_w]);

    // Rebaje de alivio para componentes SMD centrales
    translate([cx - smd_relief_w/2, as_pocket_depth - 0.1, optical_z - smd_relief_h/2])
        cube([smd_relief_w, smd_relief_depth + 0.1, smd_relief_h]);

    // Rebaje inferior para pines soldados
    translate([cx - 9.0, -0.1, optical_z - as_pocket_h/2 - 2.5])
        cube([18.0, as_pocket_depth + 0.1, 4.0]);

    // 4 orificios para tornillos de fijación M2 / M2.5
    for (dx = [-hole_pitch_w/2, hole_pitch_w/2]) {
        for (dz = [-hole_pitch_h/2, hole_pitch_h/2]) {
            translate([cx + dx, as_pocket_depth - 0.1, optical_z + dz])
                rotate([-90, 0, 0])
                    cylinder(h = mount_screw_len, d = mount_screw_dia);
        }
    }
}

// Montura Cara X=0 para la Placa LED
module cavidad_modulo_led() {
    rotate([0, 0, -90])
        translate([-block_w, 0, 0]) {
            // Canal óptico de emisión
            translate([cx, -1.0, optical_z])
                rotate([-90, 0, 0])
                    cylinder(h = cy + 1.0, d = optic_hole_dia);

            // Bolsillo del PCB
            translate([cx - led_pocket_w/2, -0.1, optical_z - led_pocket_h/2])
                cube([led_pocket_w, led_pocket_depth + 0.1, led_pocket_h]);

            // Ranuras laterales
            translate([cx - (led_pocket_w + 6.0)/2, -0.1, optical_z - 3.5])
                cube([led_pocket_w + 6.0, led_pocket_depth + 1.0, 7.0]);

            // Desahogo inferior
            translate([cx - 9.0, -0.1, optical_z - led_pocket_h/2 - 2.0])
                cube([18.0, led_pocket_depth + 0.1, 3.5]);

            // Orificios para tornillos M2 / M2.5
            for (dx = [-hole_pitch_w/2, hole_pitch_w/2]) {
                for (dz = [-hole_pitch_h/2, hole_pitch_h/2]) {
                    translate([cx + dx, led_pocket_depth - 0.1, optical_z + dz])
                        rotate([-90, 0, 0])
                            cylinder(h = mount_screw_len, d = mount_screw_dia);
                }
            }
        }
}

// Tapa estanca a la luz
module tapa_estanca() {
    cap_clearance = 0.25;
    cap_wall      = 2.0;
    cap_inner_dia = collar_od + cap_clearance * 2;
    cap_outer_dia = cap_inner_dia + cap_wall * 2;
    cap_inner_h   = collar_h + 1.5;
    cap_total_h   = cap_inner_h + 2.0;

    union() {
        difference() {
            cylinder(h = cap_total_h, d = cap_outer_dia);

            translate([0, 0, -0.1])
                cylinder(h = cap_inner_h + 0.1, d = cap_inner_dia);

            translate([0, 0, -0.1])
                cylinder(h = 1.0, d1 = cap_inner_dia + 1.5, d2 = cap_inner_dia);
        }

        // Tirador estriado superior
        translate([0, 0, cap_total_h]) {
            cylinder(h = 4.0, d = 12.0);
            for (a = [0 : 60 : 360]) {
                rotate([0, 0, a])
                    translate([6.0, 0, 2.0])
                        cylinder(h = 4.0, d = 1.2, center = true);
            }
        }
    }
}

// Cubo redondeado auxiliar
module rounded_cube(size, r) {
    x = size[0];
    y = size[1];
    z = size[2];
    hull() {
        translate([r, r, 0])         cylinder(h = z, r = r);
        translate([x - r, r, 0])     cylinder(h = z, r = r);
        translate([r, y - r, 0])     cylinder(h = z, r = r);
        translate([x - r, y - r, 0]) cylinder(h = z, r = r);
    }
}

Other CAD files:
3_Diseño3D/2_CASE_MEGA_CUBO/case_cubo2.FCStd
3_Diseño3D/3_PRUEBAS_VARIOS/3D/sistema_agarre_fr4-Body.stl
3_Diseño3D/3_PRUEBAS_VARIOS/3D/soporte5.scad
3_Diseño3D/3_PRUEBAS_VARIOS/3D/caja_base.scad
1_Circuito/1_Transmisor/1_TESTS/3_TEST_KICAD/shield_arduino/Librerias_step/nokia-5110-lcd-graphic-84x48-pixel-arduiono-compatible-blue-board-1.snapshot.2/Nokia LCD.igs
1_Circuito/1_Transmisor/1_TESTS/3_TEST_KICAD/shield_arduino/Librerias_step/nokia-5110-lcd-graphic-84x48-pixel-arduiono-compatible-blue-board-1.snapshot.2/Nokia LCD.ipt
1_Circuito/1_Transmisor/1_TESTS/3_TEST_KICAD/shield_arduino/Librerias_step/nokia-5110-lcd-graphic-84x48-pixel-arduiono-compatible-blue-board-1.snapshot.2/Nokia LCD.obj
1_Circuito/1_Transmisor/1_TESTS/3_TEST_KICAD/shield_arduino/Librerias_step/nokia-5110-lcd-graphic-84x48-pixel-arduiono-compatible-blue-board-1.snapshot.2/Nokia LCD.stl
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

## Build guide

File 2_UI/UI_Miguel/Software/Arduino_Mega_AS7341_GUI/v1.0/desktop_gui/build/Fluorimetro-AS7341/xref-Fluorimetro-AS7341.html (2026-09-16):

# modulegraph cross reference for app.py, pyi_rth_inspect.py, pyi_rth_pkgutil.py, pyi_rth_pyqt6.py

app.py Script

imports: PyQt6.QtWidgets • __future__ • _collections_abc • _weakrefset • abc • codecs • collections • collections.abc • copyreg • encodings • encodings.aliases • encodings.ascii • encodings.base64_codec • encodings.big5 • encodings.big5hkscs • encodings.bz2_codec • encodings.charmap • encodings.cp037 • encodings.cp1006 • encodings.cp1026 • encodings.cp1125 • encodings.cp1140 • encodings.cp1250 • encodings.cp1251 • encodings.cp1252 • encodings.cp1253 • encodings.cp1254 • encodings.cp1255 • encodings.cp1256 • encodings.cp1257 • encodings.cp1258 • encodings.cp273 • encodings.cp424 • encodings.cp437 • encodings.cp500 • encodings.cp720 • encodings.cp737 • encodings.cp775 • encodings.cp850 • encodings.cp852 • encodings.cp855 • encodings.cp856 • encodings.cp857 • encodings.cp858 • encodings.cp860 • encodings.cp861 • encodings.cp862 • encodings.cp863 • encodings.cp864 • encodings.cp865 • encodings.cp866 • encodings.cp869 • encodings.cp874 • encodings.cp875 • encodings.cp932 • encodings.cp949 • encodings.cp950 • encodings.euc_jis_2004 • encodings.euc_jisx0213 • encodings.euc_jp • encodings.euc_kr • encodings.gb18030 • encodings.gb2312 • encodings.gbk • encodings.hex_codec • encodings.hp_roman8 • encodings.hz • encodings.idna • encodings.iso2022_jp • encodings.iso2022_jp_1 • encodings.iso2022_jp_2 • encodings.iso2022_jp_2004 • encodings.iso2022_jp_3 • encodings.iso2022_jp_ext • encodings.iso2022_kr • encodings.iso8859_1 • encodings.iso8859_10 • encodings.iso8859_11 • encodings.iso8859_13 • encodings.iso8859_14 • encodings.iso8859_15 • encodings.iso8859_16 • encodings.iso8859_2 • encodings.iso8859_3 • encodings.iso8859_4 • encodings.iso8859_5 • encodings.iso8859_6 • encodings.iso8859_7 • encodings.iso8859_8 • encodings.iso8859_9 • encodings.johab • encodings.koi8_r • encodings.koi8_t • encodings.koi8_u • encodings.kz1048 • encodings.latin_1 • encodings.mac_arabic • encodings.mac_croatian • encodings.mac_cyrillic • encodings.mac_farsi • encodings.mac_greek • encodings.mac_iceland • encodings.mac_latin2 • encodings.mac_roman • encodings.mac_romanian • encodings.mac_turkish • encodings.mbcs • encodings.oem • encodings.palmos • encodings.ptcp154 • encodings.punycode • encodings.quopri_codec • encodings.raw_unicode_escape • encodings.rot_13 • encodings.shift_jis • encodings.shift_jis_2004 • encodings.shift_jisx0213 • encodings.tis_620 • encodings.undefined • encodings.unicode_escape • encodings.utf_16 • encodings.utf_16_be • encodings.utf_16_le • encodings.utf_32 • encodings.utf_32_be • encodings.utf_32_le • encodings.utf_7 • encodings.utf_8 • encodings.utf_8_sig • encodings.uu_codec • encodings.zlib_codec • enum • functools • genericpath • heapq • io • keyword • linecache • locale • main_window • ntpath • operator • os • posixpath • pyi_rth_inspect.py • pyi_rth_pkgutil.py • pyi_rth_pyqt6.py • re • re._casefix • re._compiler • re._constants • re._parser • reprlib • sre_compile • sre_constants • sre_parse • stat • sys • traceback • types • warnings • weakref

pyi_rth_inspect.py Script

imports: inspect • os • sys • zipfile

imported by: app.py

pyi_rth_pkgutil.py Script

imports: pkgutil • pyimod02_importers

imported by: app.py

pyi_rth_pyqt6.py Script

imports: _pyi_rth_utils • _pyi_rth_utils.qt • os • sys

imported by: app.py

'System.IO' MissingModule

imported by: serial.serialcli

'java.lang' MissingModule

imported by: platform

PyQt6 Package

imports: PyQt6.QtCore • PyQt6.QtGui • PyQt6.sip • os • pkgutil • sys

imported by: PyQt6.QtCore • PyQt6.QtGui • PyQt6.QtWidgets • PyQt6.sip

PyQt6.QtCore D:\DOCUMENTOS\PROJECTS\Fluorimetro_lowcost\.venv\Lib\site-packages\PyQt6\QtCore.pyd

imports: PyQt6 • PyQt6.sip • collections • datetime • enum • re • typing • warnings

imported by: PyQt6 • PyQt6.QtGui • PyQt6.QtWidgets • calibration_plot • display_mirror • experiments • main_window • results_quality • serial_client • spectral_plot • telemetry_writer

PyQt6.QtGui D:\DOCUMENTOS\PROJECTS\Fluorimetro_lowcost\.venv\Lib\site-packages\PyQt6\QtGui.pyd

imports: PyQt6 • PyQt6.QtCore • PyQt6.sip • collections • datetime • enum • re • typing • warnings

imported by: PyQt6 • PyQt6.QtWidgets • calibration_plot • main_window • spectral_plot • theme

PyQt6.QtWidgets D:\DOCUMENTOS\PROJECTS\Fluorimetro_lowcost\.venv\Lib\site-packages\PyQt6\QtWidgets.pyd

imports: PyQt6 • PyQt6.QtCore • PyQt6.QtGui • PyQt6.sip • collections • datetime • enum • re • typing • warnings

imported by: app.py • calibration_plot • display_mirror • experiments • main_window • results_quality • spectral_plot • theme

PyQt6.sip D:\DOCUMENTOS\PROJECTS\Fluorimetro_lowcost\.venv\Lib\site-packages\PyQt6\sip.cp312-win_amd64.pyd

imports: PyQt6 • typing

imported by: PyQt6 • PyQt6.QtCore • PyQt6.QtGui • PyQt6.QtWidgets

System MissingModule

imported by: serial.serialcli

__future__ SourceModule

imported by: app.py • exporter • main_window • protocol • serial • serial.serialcli • serial.serialjava • serial.serialposix • serial.serialutil • serial.serialwin32 • serial.tools.list_ports • serial.tools.list_ports_common • serial.tools.list_ports_linux • serial.tools.list_ports_osx • serial.tools.list_ports_posix • serial.tools.list_ports_windows • serial.win32 • serial_client • spectral_plot • telemetry_writer

_abc (builtin module)

imported by: abc

_ast (builtin module)

imported by: ast

_bisect (builtin module)

imported by: bisect

_blake2 (builtin module)

imported by: hashlib

_bz2 C:\Users\47470482\AppData\Roaming\uv\python\cpython-3.12-windows-x86_64-none\DLLs\_bz2.pyd

imported by: bz2

_codecs (builtin module)

imported by: codecs

_codecs_cn (builtin module)

imported by: encodings.gb18030 • encodings.gb2312 • encodings.gbk • encodings.hz

_codecs_hk (builtin module)

imported by: encodings.big5hkscs

_codecs_iso2022 (builtin module)

imported by: encodings.iso2022_jp • encodings.iso2022_jp_1 • encodings.iso2022_jp_2 • encodings.iso2022_jp_2004 • encodings.iso2022_jp_3 • encodings.iso2022_jp_ext • encodings.iso2022_kr

_codecs_jp (builtin module)

imported by: encodings.cp932 • encodings.euc_jis_2004 • encodings.euc_jisx0213 • encodings.euc_jp • encodings.shift_jis • encodings.shift_jis_2004 • encodings.shift_jisx0213

_codecs_kr (builtin module)

imported by: encodings.cp949 • encodings.euc_kr • encodings.johab

_codecs_tw (builtin module)

imported by: encodings.big5 • encodings.cp950

_collections (builtin module)

imported by: collections • threading

_collections_abc SourceModule

imports: abc • sys • warnings

imported by: app.py • collections • collections.abc • contextlib • locale • os • pathlib • random • types • weakref

_compat_pickle SourceModule

imported by: _pickle • pickle

_compression SourceModule

imports: io • sys

imported by: bz2 • gzip • lzma

_contextvars (builtin module)

imported by: contextvars

_csv (builtin module)

imported by: csv

_ctypes C:\Users\47470482\AppData\Roaming\uv\python\cpython-3.12-windows-x86_64-none\DLLs\_ctypes.pyd

imported by: ctypes

_datetime (builtin module)

imports: _strptime • time

imported by: datetime

_decimal C:\Users\47470482\AppData\Roaming\uv\python\cpython-3.12-windows-x86_64-none\DLLs\_decimal.pyd

imported by: decimal

_frozen_importlib ExcludedModule

imported by: importlib • importlib.abc • zipimport

_frozen_importlib_external MissingModule

imported by: importlib • importlib._bootstrap • importlib.abc • zipimport

_functools (builtin module)

imported by: functools

_hashlib C:\Users\47470482\AppData\Roaming\uv\python\cpython-3.12-windows-x86_64-none\DLLs\_hashlib.pyd

imported by: hashlib

_heapq (builtin module)

imported by: heapq

_imp (builtin module)

imported by: importlib • importlib._bootstrap_external • importlib.util • zipimport

_io (builtin module)

imported by: importlib._bootstrap_external • io • zipimport

_json (builtin module)

imports: json.decoder

imported by: json.decoder • json.encoder • json.scanner

_locale (builtin module)

imported by: locale

_lzma C:\Users\47470482\AppData\Roaming\uv\python\cpython-3.12-windows-x86_64-none\DLLs\_lzma.pyd

imported by: lzma

_md5 (builtin module)

imported by: hashlib

_multibytecodec (builtin module)

imported by: encodings.big5 • encodings.big5hkscs • encodings.cp932 • encodings.cp949 • encodings.cp950 • encodings.euc_jis_2004 • encodings.euc_jisx0213 • encodings.euc_jp • encodings.euc_kr • encodings.gb18030 • encodings.gb2312 • encodings.gbk • encodings.hz • encodings.iso2022_jp • encodings.iso2022_jp_1 • encodings.iso2022_jp_2 • encodings.iso2022_jp_2004 • encodings.iso2022_jp_3 • encodings.iso2022_jp_ext • encodings.iso2022_kr • encodings.johab • encodings.shift_jis • encodings.shift_jis_2004 • encodings.shift_jisx0213

_opcode (builtin module)

imported by: opcode

_operator (builtin module)

imported by: operator

_pickle (builtin module)

imports: _compat_pickle • codecs • copyreg

imported by: pickle

_posixsubprocess MissingModule

imports: gc

imported by: subprocess

_py_abc SourceModule

imports: _weakrefset

imported by: abc

_pydatetime SourceModule

imports: _strptime • math • operator • sys • time • warnings

imported by: datetime

_pydecimal SourceModule

imports: collections • contextvars • itertools • locale • math • numbers • re • sys

imported by: decimal

_pyi_rth_utils Package

imports: _pyi_rth_utils.qt • os • sys

imported by: _pyi_rth_utils.qt • pyi_rth_pyqt6.py

_pyi_rth_utils.qt SourceModule

imports: _pyi_rth_utils • atexit • importlib • os

imported by: _pyi_rth_utils • pyi_rth_pyqt6.py

_queue C:\Users\47470482\AppData\Roaming\uv\python\cpython-3.12-windows-x86_64-none\DLLs\_queue.pyd

imported by: queue

_random (builtin module)

imported by: random

_sha1 (builtin module)

imported by: hashlib

_sha2 (builtin module)

imported by: hashlib • random

_sha3 (builtin module)

imported by: hashlib

_signal (builtin module)

imported by: signal

_socket C:\Users\47470482\AppData\Roaming\uv\python\cpython-3.12-windows-x86_64-none\DLLs\_socket.pyd

imported by: socket

_sre (builtin module)

imports: copy • re

imported by: re • re._compiler • re._constants

_stat (builtin module)

imported by: stat

_statistics (builtin module)

imported by: statistics

_string (builtin module)

imported by: string

_strptime SourceModule

imports: _thread • calendar • datetime • locale • re • time

imported by: _datetime • _pydatetime • time

_struct (builtin module)

imported by: struct

_thread (builtin module)

imported by: _strptime • dataclasses • functools • reprlib • tempfile • threading

_threading_local SourceModule

imports: contextlib • threading • weakref

imported by: threading

_tokenize (builtin module)

imported by: tokenize

_tracemalloc (builtin module)

imported by: tracemalloc

_typing (builtin module)

imported by: typing

_uuid C:\Users\47470482\AppData\Roaming\uv\python\cpython-3.12-windows-x86_64-none\DLLs\_uuid.pyd

imported by: uuid

_warnings (builtin module)

imported by: importlib._bootstrap_external • warnings • zipimport

_weakref (builtin module)

imported by: _weakrefset • collections • weakref

_weakrefset SourceModule

imports: _weakref • types

imported by: _py_abc • app.py • threading • weakref

_winapi (builtin module)

imported by: encodings • ntpath • shutil • subprocess

_winreg MissingModule

imported by: platform

_wmi C:\Users\47470482\AppData\Roaming\uv\python\cpython-3.12-windows-x86_64-none\DLLs\_wmi.pyd

imported by: platform

abc SourceModule

imports: _abc • _py_abc

imported by: _collections_abc • app.py • contextlib • dataclasses • email._policybase • functools • importlib._abc • importlib.abc • importlib.metadata • importlib.resources.abc • inspect • io • numbers • os • selectors • typing

analysis SourceModule

imports: copy • datetime • math • protocol • statistics • uuid

imported by: experiment_validation • experiments • fluorometry • results_quality

argparse SourceModule

imports: copy • gettext • os • re • shutil • sys • textwrap • warnings

imported by: ast • calendar • dis • gzip • inspect • py_compile • serial.tools.list_ports • tarfile • tokenize • uuid • zipfile

array (builtin module)

imported by: serial.serialposix • serial.serialutil • socket

ast SourceModule

imports: _ast • argparse • collections • contextlib • enum • inspect • re • sys • warnings

imported by: inspect • traceback

atexit (builtin module)

imported by: _pyi_rth_utils.qt • logging • weakref

base64 SourceModule

imports: binascii • getopt • re • struct • sys

imported by: email._encoded_words • email.base64mime • email.encoders • encodings.base64_codec

binascii (builtin module)

imported by: base64 • email._encoded_words • email.base64mime • email.contentmanager • email.header • email.message • encodings.hex_codec • encodings.uu_codec • quopri • zipfile

bisect SourceModule

imports: _bisect

imported by: random • statistics

builtins (builtin module)

imported by: bz2 • codecs • enum • gettext • gzip • inspect • locale • lzma • operator • reprlib • subprocess • tarfile • tokenize • warnings

bz2 SourceModule

imports: _bz2 • _compression • builtins • io • os

imported by: encodings.bz2_codec • shutil • tarfile • zipfile

calendar SourceModule

imports: argparse • datetime • enum • itertools • locale • sys • warnings

imported by: _strptime • email._parseaddr

calibration_plot SourceModule

imports: PyQt6.QtCore • PyQt6.QtGui • PyQt6.QtWidgets

imported by: experiments

codecs SourceModule

imports: _codecs • builtins • encodings • sys

imported by: _pickle • app.py • encodings • encodings.ascii • encodings.base64_codec • encodings.big5 • encodings.big5hkscs • encodings.bz2_codec • encodings.charmap • encodings.cp037 • encodings.cp1006 • encodings.cp1026 • encodings.cp1125 • encodings.cp1140 • encodings.cp1250 • encodings.cp1251 • encodings.cp1252 • encodings.cp1253 • encodings.cp1254 • encodings.cp1255 • encodings.cp1256 • encodings.cp1257 • encodings.cp1258 • encodings.cp273 • encodings.cp424 • encodings.cp437 • encodings.cp500 • encodings.cp720 • encodings.cp737 • encodings.cp775 • encodings.cp850 • encodings.cp852 • encodings.cp855 • encodings.cp856 • encodings.cp857 • encodings.cp858 • encodings.cp860 • encodings.cp861 • encodings.cp862 • encodings.cp863 • encodings.cp864 • encodings.cp865 • encodings.cp866 • encodings.cp869 • encodings.cp874 • encodings.cp875 • encodings.cp932 • encodings.cp949 • encodings.cp950 • encodings.euc_jis_2004 • encodings.euc_jisx0213 • encodings.euc_jp • encodings.euc_kr • encodings.gb18030 • encodings.gb2312 • encodings.gbk • encodings.hex_codec • encodings.hp_roman8 • encodings.hz • encodings.idna • encodings.iso2022_jp • encodings.iso2022_jp_1 • encodings.iso2022_jp_2 • encodings.iso2022_jp_2004 • encodings.iso2022_jp_3 • encodings.iso2022_jp_ext • encodings.iso2022_kr • encodings.iso8859_1 • encodings.iso8859_10 • encodings.iso8859_11 • encodings.iso8859_13 • encodings.iso8859_14 • encodings.iso8859_15 • encodings.iso8859_16 • encodings.iso8859_2 • encodings.iso8859_3 • encodings.iso8859_4 • encodings.iso8859_5 • encodings.iso8859_6 • encodings.iso8859_7 • encodings.iso8859_8 • encodings.iso8859_9 • encodings.johab • encodings.koi8_r • encodings.koi8_t • encodings.koi8_u • encodings.kz1048 • encodings.latin_1 • encodings.mac_arabic • encodings.mac_croatian • encodings.mac_cyrillic • encodings.mac_farsi • encodings.mac_greek • encodings.mac_iceland • encodings.mac_latin2 • encodings.mac_roman • encodings.mac_romanian • encodings.mac_turkish • encodings.mbcs • encodings.oem • encodings.palmos • encodings.ptcp154 • encodings.punycode • encodings.quopri_codec • encodings.raw_unicode_escape • encodings.rot_13 • encodings.shift_jis • encodings.shift_jis_2004 • encodings.shift_jisx0213 • encodings.tis_620 • encodings.undefined • encodings.unicode_escape • encodings.utf_16 • encodings.utf_16_be • encodings.utf_16_le • encodings.utf_32 • encodings.utf_32_be • encodings.utf_32_le • encodings.utf_7 • encodings.utf_8 • encodings.utf_8_sig • encodings.uu_codec • encodings.zlib_codec • json • pickle • tokenize

collections Package

imports: _collections • _collections_abc • _weakref • copy • heapq • itertools • keyword • operator • reprlib • sys

imported by: PyQt6.QtCore • PyQt6.QtGui • PyQt6.QtWidgets • _pydecimal • app.py • ast • collections.abc • contextlib • dis • email.feedparser • functools • importlib.metadata • importlib.metadata._collections • importlib.resources.readers • inspect • pkgutil • platform • pprint • queue • selectors • shutil • statistics • string • threading • tokenize • typing • urllib.parse

collections.abc SourceModule

imports: _collections_abc • collections

imported by: app.py • inspect • logging • selectors • traceback • tracemalloc • typing

contextlib SourceModule

imports: _collections_abc • abc • collections • functools • os • sys • types

imported by: _threading_local • ast • glob • importlib.metadata • importlib.resources._adapters • importlib.resources._common • subprocess • traceback • typing • zipfile._path

contextvars SourceModule

imports: _contextvars

imported by: _pydecimal

copy SourceModule

imports: copyreg • types • weakref

imported by: _sre • analysis • argparse • collections • dataclasses • email.generator • experiment_validation • experiments • fluorometry • gettext • results_quality • tarfile • weakref

copyreg SourceModule

imports: functools • operator

imported by: _pickle • app.py • copy • pickle • re • typing

csv SourceModule

imports: _csv • io • re • types

imported by: experiments • exporter • importlib.metadata • results_quality

ctypes Package

imports: _ctypes • ctypes._endian • nt • os • struct • sys • types

imported by: ctypes._endian • ctypes.wintypes • serial.serialwin32 • serial.tools.list_ports_osx • serial.tools.list_ports_windows • serial.win32

ctypes._endian SourceModule

imports: ctypes • sys

imported by: ctypes

ctypes.wintypes SourceModule

imports: ctypes

imported by: serial.tools.list_ports_windows • serial.win32

dataclasses SourceModule

imports: _thread • abc • copy • functools • inspect • itertools • keyword • re • sys • types

imported by: pprint • telemetry_writer

datetime SourceModule

imports: _datetime • _pydatetime • time

imported by: PyQt6.QtCore • PyQt6.QtGui • PyQt6.QtWidgets • _strptime • analysis • calendar • email.utils • exporter • fluorometry • main_window • results_quality • telemetry_writer

decimal SourceModule

imports: _decimal • _pydecimal

imported by: fractions • statistics

dis SourceModule

imports: argparse • collections • io • opcode • sys • types

imported by: inspect

display_mirror SourceModule

imports: PyQt6.QtCore • PyQt6.QtWidgets • protocol

imported by: main_window

email Package

imports: email._header_value_parser • email.charset • email.errors • email.header • email.parser

imported by: email._encoded_words • email._header_value_parser • email._parseaddr • email._policybase • email.base64mime • email.charset • email.contentmanager • email.encoders • email.errors • email.feedparser • email.generator • email.header • email.headerregistry • email.iterators • email.message • email.parser • email.policy • email.quoprimime • email.utils • importlib.metadata

email._encoded_words SourceModule

imports: base64 • binascii • email • email.errors • functools • re • string

imported by: email._header_value_parser • email.message

email._header_value_parser SourceModule

imports: email • email._encoded_words • email.errors • email.utils • operator • re • string • sys • urllib

imported by: email • email.headerregistry

email._parseaddr SourceModule

imports: calendar • email • time

imported by: email.utils

email._policybase SourceModule

imports: abc • email • email.charset • email.header • email.utils

imported by: email.feedparser • email.message • email.parser • email.policy

email.base64mime SourceModule

imports: base64 • binascii • email

imported by: email.charset • email.header

email.charset SourceModule

imports: email • email.base64mime • email.encoders • email.errors • email.quoprimime • functools

imported by: email • email._policybase • email.contentmanager • email.header • email.message • email.utils

email.contentmanager SourceModule

imports: binascii • email • email.charset • email.errors • email.message • email.quoprimime

imported by: email.policy

email.encoders SourceModule

imports: base64 • email • quopri

imported by: email.charset

email.errors SourceModule

imports: email

imported by: email • email._encoded_words • email._header_value_parser • email.charset • email.contentmanager • email.feedparser • email.generator • email.header • email.headerregistry • email.message

email.feedparser SourceModule

imports: collections • email • email._policybase • email.errors • email.message • io • re

imported by: email.parser

email.generator SourceModule

imports: copy • email • email.errors • email.utils • io • random • re • sys • time

imported by: email.message

email.header SourceModule

imports: binascii • email • email.base64mime • email.charset • email.errors • email.quoprimime • re

imported by: email • email._policybase

email.headerregistry SourceModule

imports: email • email._header_value_parser • email.errors • email.utils • types

imported by: email.policy

email.iterators SourceModule

imports: email • io • sys

imported by: email.message

email.message SourceModule

imports: binascii • email • email._encoded_words • email._policybase • email.charset • email.errors • email.generator • email.iterators • email.policy • email.utils • io • quopri • re

imported by: email.contentmanager • email.feedparser • email.policy • importlib.metadata._adapters

email.parser SourceModule

imports: email • email._policybase • email.feedparser • io

imported by: email

email.policy SourceModule

imports: email • email._policybase • email.contentmanager • email.headerregistry • email.message • email.utils • re • sys

imported by: email.message

email.quoprimime SourceModule

imports: email • re • string

imported by: email.charset • email.contentmanager • email.header

email.utils SourceModule

imports: datetime • email • email._parseaddr • email.charset • os • random • re • socket • time • urllib.parse • warnings

imported by: email._header_value_parser • email._policybase • email.generator • email.headerregistry • email.message • email.policy

encodings Package

imports: _winapi • codecs • encodings • encodings.aliases • encodings.ascii • encodings.base64_codec • encodings.big5 • encodings.big5hkscs • encodings.bz2_codec • encodings.charmap • encodings.cp037 • encodings.cp1006 • encodings.cp1026 • encodings.cp1125 • encodings.cp1140 • encodings.cp1250 • encodings.cp1251 • encodings.cp1252 • encodings.cp1253 • encodings.cp1254 • encodings.cp1255 • encodings.cp1256 • encodings.cp1257 • encodings.cp1258 • encodings.cp273 • encodings.cp424 • encodings.cp437 • encodings.cp500 • encodings.cp720 • encodings.cp737 • encodings.cp775 • encodings.cp850 • encodings.cp852 • encodings.cp855 • encodings.cp856 • encodings.cp857 • encodings.cp858 • encodings.cp860 • encodings.cp861 • encodings.cp862 • encodings.cp863 • encodings.cp864 • encodings.cp865 • encodings.cp866 • encodings.cp869 • encodings.cp874 • encodings.cp875 • encodings.cp932 • encodings.cp949 • encodings.cp950 • encodings.euc_jis_2004 • encodings.euc_jisx0213 • encodings.euc_jp • encodings.euc_kr • encodings.gb18030 • encodings.gb2312 • encodings.gbk • encodings.hex_codec • encodings.hp_roman8 • encodings.hz • encodings.idna • encodings.iso2022_jp • encodings.iso2022_jp_1 • encodings.iso2022_jp_2 • encodings.iso2022_jp_2004 • encodings.iso2022_jp_3 • encodings.iso2022_jp_ext • encodings.iso2022_kr • encodings.iso8859_1 • encodings.iso8859_10 • encodings.iso8859_11 • encodings.iso8859_13 • encodings.iso8859_14 • encodings.iso8859_15 • encodings.iso8859_16 • encodings.iso8859_2 • encodings.iso8859_3 • encodings.iso8859_4 • encodings.iso8859_5 • encodings.iso8859_6 • encodings.iso8859_7 • encodings.iso8859_8 • encodings.iso8859_9 • encodings.johab • encodings.koi8_r • encodings.koi8_t • encodings.koi8_u • encodings.kz1048 • encodings.latin_1 • encodings.mac_arabic • encodings.mac_croatian • encodings.mac_cyrillic • encodings.mac_farsi • encodings.mac_greek • encodings.mac_iceland • encodings.mac_latin2 • encodings.mac_roman • encodings.mac_romanian • encodings.mac_turkish • encodings.mbcs • encodings.oem • encodings.palmos • encodings.ptcp154 • encodings.punycode • encodings.quopri_codec • encodings.raw_unicode_escape • encodings.rot_13 • encodings.shift_jis • encodings.shift_jis_2004 • encodings.shift_jisx0213 • encodings.tis_620 • encodings.undefined • encodings.unicode_escape • encodings.utf_16 • encodings.utf_16_be • encodings.utf_16_le • encodings.utf_32 • encodings.utf_32_be • encodings.utf_32_le • encodings.utf_7 • encodings.utf_8 • encodings.utf_8_sig • encodings.uu_codec • encodings.zlib_codec • sys

imported by: app.py • codecs • encodings • encodings.aliases • encodings.ascii • encodings.base64_codec • encodings.big5 • encodings.big5hkscs • encodings.bz2_codec • encodings.charmap • encodings.cp037 • encodings.cp1006 • encodings.cp1026 • encodings.cp1125 • encodings.cp1140 • encodings.cp1250 • encodings.cp1251 • encodings.cp1252 • encodings.cp1253 • encodings.cp1254 • encodings.cp1255 • encodings.cp1256 • encodings.cp1257 • encodings.cp1258 • encodings.cp273 • encodings.cp424 • encodings.cp437 • encodings.cp500 • encodings.cp720 • encodings.cp737 • encodings.cp775 • encodings.cp850 • encodings.cp852 • encodings.cp855 • encodings.cp856 • encodings.cp857 • encodings.cp858 • encodings.cp860 • encodings.cp861 • encodings.cp862 • encodings.cp863 • encodings.cp864 • encodings.cp865 • encodings.cp866 • encodings.cp869 • encodings.cp874 • encodings.cp875 • encodings.cp932 • encodings.cp949 • encodings.cp950 • encodings.euc_jis_2004 • encodings.euc_jisx0213 • encodings.euc_jp • encodings.euc_kr • encodings.gb18030 • encodings.gb2312 • encodings.gbk • encodings.hex_codec • encodings.hp_roman8 • encodings.hz • encodings.idna • encodings.iso2022_jp • encodings.iso2022_jp_1 • encodings.iso2022_jp_2 • encodings.iso2022_jp_2004 • encodings.iso2022_jp_3 • encodings.iso2022_jp_ext • encodings.iso2022_kr • encodings.iso8859_1 • encodings.iso8859_10 • encodings.iso8859_11 • encodings.iso8859_13 • encodings.iso8859_14 • encodings.iso8859_15 • encodings.iso8859_16 • encodings.iso8859_2 • encodings.iso8859_3 • encodings.iso8859_4 • encodings.iso8859_5 • encodings.iso8859_6 • encodings.iso8859_7 • encodings.iso8859_8 • encodings.iso8859_9 • encodings.johab • encodings.koi8_r • encodings.koi8_t • encodings.koi8_u • encodings.kz1048 • encodings.latin_1 • encodings.mac_arabic • encodings.mac_croatian • encodings.mac_cyrillic • encodings.mac_farsi • encodings.mac_greek • encodings.mac_iceland • encodings.mac_latin2 • encodings.mac_roman • encodings.mac_romanian • encodings.mac_turkish • encodings.mbcs • encodings.oem • encodings.palmos • encodings.ptcp154 • encodings.punycode • encodings.quopri_codec • encodings.raw_unicode_escape • encodings.rot_13 • encodings.shift_jis • encodings.shift_jis_2004 • encodings.shift_jisx0213 • encodings.tis_620 • encodings.undefined • encodings.unicode_escape • encodings.utf_16 • encodings.utf_16_be • encodings.utf_16_le • encodings.utf_32 • encodings.utf_32_be • encodings.utf_32_le • encodings.utf_7 • encodings.utf_8 • encodings.utf_8_sig • encodings.uu_codec • encodings.zlib_codec • locale

encodings.aliases SourceModule

imports: encodings

imported by: app.py • encodings • locale

encodings.ascii SourceModule

imports: codecs • encodings

imported by: app.py • encodings

encodings.base64_codec SourceModule

imports: base64 • codecs • encodings

imported by: app.py • encodings

encodings.big5 SourceModule

imports: _codecs_tw • _multibytecodec • codecs • encodings

imported by: app.py • encodings

encodings.big5hkscs SourceModule

imports: _codecs_hk • _multibytecodec • codecs • encodings

imported by: app.py • encodings

encodings.bz2_codec SourceModule

imports: bz2 • codecs • encodings

imported by: app.py • encodings

encodings.charmap SourceModule

imports: codecs • encodings

imported by: app.py • encodings

encodings.cp037 SourceModule

imports: codecs • encodings

imported by: app.py • encodings

encodings.cp1006 SourceModule

imports: codecs • encodings

imported by: app.py • encodings

encodings.cp1026 SourceModule

imports: codecs • encodings

imported by: app.py • encodings

encodings.cp1125 SourceModule

imports: codecs • encodings

imported by: app.py • encodings

encodings.cp1140 SourceModule

imports: codecs • encodings

imported by: app.py • encodings

encodings.cp1250 SourceModule

imports: codecs • encodings

imported by: app.py • encodings

encodings.cp1251 SourceModule

imports: codecs • encodings

imported by: app.py • encodings

encodings.cp1252 SourceModule

imports: codecs • encodings

imported by: app.py • encodings

encodings.cp1253 SourceModule

imports: codecs • encodings

imported by: app.py • encodings

encodings.cp1254 SourceModule

imports: codecs • encodings

imported by: app.py • encodings

encodings.cp1255 SourceModule

imports: codecs • encodings

imported by: app.py • encodings

encodings.cp1256 SourceModule

imports: codecs • encodings

imported by: app.py • encodings

encodings.cp1257 SourceModule

imports: codecs • encodings

imported by: app.py • encodings

encodings.cp1258 SourceModule

imports: codecs • encodings

imported by: app.py • encodings

encodings.cp273 SourceModule

imports: codecs • encodings

imported by: app.py • encodings

encodings.cp424 SourceModule

imports: codecs • encodings

imported by: app.py • encodings

encodings.cp437 SourceModule

imports: codecs • encodings

imported by: app.py • encodings

encodings.cp500 SourceModule

imports: codecs • encodings

imported by: app.py • encodings

encodings.cp720 SourceModule

imports: codecs • encodings

imported by: app.py • encodings

encodings.cp737 SourceModule

imports: codecs • encodings

imported by: app.py • encodings

encodings.cp775 SourceModule

imports: codecs • encodings

imported by: app.py • encodings

encodings.cp850 SourceModule

imports: codecs • encodings

imported by: app.py • encodings

encodings.cp852 SourceModule

imports: codecs • encodings

imported by: app.py • encodings

encodings.cp855 SourceModule

imports: codecs • encodings

imported by: app.py • encodings

encodings.cp856 SourceModule

imports: codecs • encodings

imported by: app.py • encodings

encodings.cp857 SourceModule

imports: codecs • encodings

imported by: app.py • encodings

encodings.cp858 SourceModule

imports: codecs • encodings

imported by: app.py • encodings

encodings.cp860 SourceModule

imports: codecs • encodings

imported by: app.py • encodings

encodings.cp861 SourceModule

imports: codecs • encodings

imported by: app.py • encodings

encodings.cp862 SourceModule

imports: codecs • encodings

imported by: app.py • encodings

encodings.cp863 SourceModule

imports: codecs • encodings

imported by: app.py • encodings

encodings.cp864 SourceModule

imports: codecs • encodings

imported by: app.py • encodings

encodings.cp865 SourceModule

imports: codecs • encodings

imported by: app.py • encodings

encodings.cp866 SourceModule

imports: codecs • encodings

imported by: app.py • encodings

encodings.cp869 SourceModule

imports: codecs • encodings

imported by: app.py • encodings

encodings.cp874 SourceModule

imports: codecs • encodings

imported by: app.py • encodings

encodings.cp875 SourceModule

imports: codecs • encodings

imported by: app.py • encodings

encodings.cp932 SourceModule

imports: _codecs_jp • _multibytecodec • codecs • encodings

imported by: app.py • encodings

encodings.cp949 SourceModule

imports: _codecs_kr • _multibytecodec • codecs • encodings

imported by: app.py • encodings

encodings.cp950 SourceModule

imports: _codecs_tw • _multibytecodec • codecs • encodings

imported by: app.py • encodings

encodings.euc_jis_2004 SourceModule

imports: _codecs_jp • _multibytecodec • codecs • encodings

imported by: app.py • encodings

encodings.euc_jisx0213 SourceModule

imports: _codecs_jp • _multibytecodec • codecs • encodings

imported by: app.py • encodings

encodings.euc_jp SourceModule

imports: _codecs_jp • _multibytecodec • codecs • encodings

imported by: app.py • encodings

encodings.euc_kr SourceModule

imports: _codecs_kr • _multibytecodec • codecs • encodings

imported by: app.py • encodings

encodings.gb18030 SourceModule

imports: _codecs_cn • _multibytecodec • codecs • encodings

imported by: app.py • encodings

encodings.gb2312 SourceModule

imports: _codecs_cn • _multibytecodec • codecs • encodings

imported by: app.py • encodings

encodings.gbk SourceModule

imports: _codecs_cn • _multibytecodec • codecs • encodings

imported by: app.py • encodings

encodings.hex_codec SourceModule

imports: binascii • codecs • encodings

imported by: app.py • encodings

encodings.hp_roman8 SourceModule

imports: codecs • encodings

imported by: app.py • encodings

encodings.hz SourceModule

imports: _codecs_cn • _multibytecodec • codecs • encodings

imported by: app.py • encodings

encodings.idna SourceModule

imports: codecs • encodings • re • stringprep • unicodedata

imported by: app.py • encodings

encodings.iso2022_jp SourceModule

imports: _codecs_iso2022 • _multibytecodec • codecs • encodings

imported by: app.py • encodings

encodings.iso2022_jp_1 SourceModule

imports: _codecs_iso2022 • _multibytecodec • codecs • encodings

imported by: app.py • encodings

encodings.iso2022_jp_2 SourceModule

imports: _codecs_iso2022 • _multibytecodec • codecs • encodings

imported by: app.py • encodings

encodings.iso2022_jp_2004 SourceModule

imports: _codecs_iso2022 • _multibytecodec • codecs • encodings

imported by: app.py • encodings

encodings.iso2022_jp_3 SourceModule

imports: _codecs_iso2022 • _multibytecodec • codecs • encodings

imported by: app.py • encodings

encodings.iso2022_jp_ext SourceModule

imports: _codecs_iso2022 • _multibytecodec • codecs • encodings

imported by: app.py • encodings

encodings.iso2022_kr SourceModule

imports: _codecs_iso2022 • _multibytecodec • codecs • encodings

imported by: app.py • encodings

encodings.iso8859_1 SourceModule

imports: codecs • encodings

imported by: app.py • encodings

encodings.iso8859_10 SourceModule

imports: codecs • encodings

imported by: app.py • encodings

encodings.iso8859_11 SourceModule

imports: codecs • encodings

imported by: app.py • encodings

encodings.iso8859_13 SourceModule

imports: codecs • encodings

imported by: app.py • encodings

encodings.iso8859_14 SourceModule

imports: codecs • encodings

imported by: app.py • encodings

encodings.iso8859_15 SourceModule

imports: codecs • encodings

imported by: app.py • encodings

encodings.iso8859_16 SourceModule

imports: codecs • encodings

imported by: app.py • encodings

encodings.iso8859_2 SourceModule

imports: codecs • encodings

imported by: app.py • encodings

encodings.iso8859_3 SourceModule

imports: codecs • encodings

imported by: app.py • encodings

encodings.iso8859_4 SourceModule

imports: codecs • encodings

imported by: app.py • encodings

encodings.iso8859_5 SourceModule

imports: codecs • encodings

imported by: app.py • encodings

encodings.iso8859_6 SourceModule

imports: codecs • encodings

imported by: app.py • encodings

encodings.iso8859_7 SourceModule

imports: codecs • encodings

imported by: app.py • encodings

encodings.iso8859_8 SourceModule

imports: codecs • encodings

imported by: app.py • encodings

encodings.iso8859_9 SourceModule

imports: codecs • encodings

imported by: app.py • encodings

encodings.johab SourceModule

imports: _codecs_kr • _multibytecodec • codecs • encodings

imported by: app.py • encodings

encodings.koi8_r SourceModule

imports: codecs • encodings

imported by: app.py • encodings

encodings.koi8_t SourceModule

imports: codecs • encodings

imported by: app.py • encodings

encodings.koi8_u SourceModule

imports: codecs • encodings

imported by: app.py • encodings

encodings.kz1048 SourceModule

imports: codecs • encodings

imported by: app.py • encodings

encodings.latin_1 SourceModule

imports: codecs • encodings

imported by: app.py • encodings

encodings.mac_arabic SourceModule

imports: codecs • encodings

imported by: app.py • encodings

encodings.mac_croatian SourceModule

imports: codecs • encodings

imported by: app.py • encodings

encodings.mac_cyrillic SourceModule

imports: codecs • encodings

imported by: app.py • encodings

encodings.mac_farsi SourceModule

imports: codecs • encodings

imported by: app.py • encodings

encodings.mac_greek SourceModule

imports: codecs • encodings

imported by: app.py • encodings

encodings.mac_iceland SourceModule

imports: codecs • encodings

imported by: app.py • encodings

encodings.mac_latin2 SourceModule

imports: codecs • encodings

imported by: app.py • encodings

encodings.mac_roman SourceModule

imports: codecs • encodings

imported by: app.py • encodings

encodings.mac_romanian SourceModule

imports: codecs • encodings

imported by: app.py • encodings

encodings.mac_turkish SourceModule

imports: codecs • encodings

imported by: app.py • encodings

encodings.mbcs SourceModule

imports: codecs • encodings

imported by: app.py • encodings

encodings.oem SourceModule

imports: codecs • encodings

imported by: app.py • encodings

encodings.palmos SourceModule

imports: codecs • encodings

imported by: app.py • encodings

encodings.ptcp154 SourceModule

imports: codecs • encodings

imported by: app.py • encodings

encodings.punycode SourceModule

imports: codecs • encodings

imported by: app.py • encodings

encodings.quopri_codec SourceModule

imports: codecs • encodings • io • quopri

imported by: app.py • encodings

encodings.raw_unicode_escape SourceModule

imports: codecs • encodings

imported by: app.py • encodings

encodings.rot_13 SourceModule

imports: codecs • encodings • sys

imported by: app.py • encodings

encodings.shift_jis SourceModule

imports: _codecs_jp • _multibytecodec • codecs • encodings

imported by: app.py • encodings

encodings.shift_jis_2004 SourceModule

imports: _codecs_jp • _multibytecodec • codecs • encodings

imported by: app.py • encodings

encodings.shift_jisx0213 SourceModule

imports: _codecs_jp • _multibytecodec • codecs • encodings

imported by: app.py • encodings

encodings.tis_620 SourceModule

imports: codecs • encodings

imported by: app.py • encodings

encodings.undefined SourceModule

imports: codecs • encodings

imported by: app.py • encodings

encodings.unicode_escape SourceModule

imports: codecs • encodings

imported by: app.py • encodings

encodings.utf_16 SourceModule

imports: codecs • encodings • sys

imported by: app.py • encodings

encodings.utf_16_be SourceModule

imports: codecs • encodings

imported by: app.py • encodings

encodings.utf_16_le SourceModule

imports: codecs • encodings

imported by: app.py • encodings

encodings.utf_32 SourceModule

imports: codecs • encodings • sys

imported by: app.py • encodings

encodings.utf_32_be SourceModule

imports: codecs • encodings

imported by: app.py • encodings

encodings.utf_32_le SourceModule

imports: codecs • encodings

imported by: app.py • encodings

encodings.utf_7 SourceModule

imports: codecs • encodings

imported by: app.py • encodings

encodings.utf_8 SourceModule

imports: codecs • encodings

imported by: app.py • encodings

encodings.utf_8_sig SourceModule

imports: codecs • encodings

imported by: app.py • encodings

encodings.uu_codec SourceModule

imports: binascii • codecs • encodings • io

imported by: app.py • encodings

encodings.zlib_codec SourceModule

imports: codecs • encodings • zlib

imported by: app.py • encodings

enum SourceModule

imports: builtins • functools • operator • sys • types • warnings

imported by: PyQt6.QtCore • PyQt6.QtGui • PyQt6.QtWidgets • app.py • ast • calendar • inspect • py_compile • re • signal • socket • uuid

errno (builtin module)

imported by: gettext • gzip • pathlib • serial.serialposix • shutil • socket • subprocess • tempfile

experiment_validation SourceModule

imports: analysis • copy • fluorometry • math • protocol

imported by: experiments

experiments SourceModule

imports: PyQt6.QtCore • PyQt6.QtWidgets • analysis • calibration_plot • copy • csv • experiment_validation • fluorometry • json • pathlib • protocol • session_store • uuid

imported by: main_window

exporter SourceModule

imports: __future__ • csv • datetime • pathlib • protocol • shutil • tempfile • typing

imported by: main_window • telemetry_writer

fcntl MissingModule

imported by: serial.serialposix • subprocess

fluorometry SourceModule

imports: analysis • copy • datetime • json • math • statistics • uuid

imported by: experiment_validation • experiments • results_quality

fnmatch SourceModule

imports: functools • os • posixpath • re

imported by: glob • pathlib • shutil • tracemalloc

fractions SourceModule

imports: decimal • functools • math • numbers • operator • re • sys

imported by: statistics

functools SourceModule

imports: _functools • _thread • abc • collections • reprlib • types • typing • weakref

imported by: app.py • contextlib • copyreg • dataclasses • email._encoded_words • email.charset • enum • fnmatch • fractions • importlib.metadata • importlib.metadata._adapters • importlib.metadata._functools • importlib.resources._common • importlib.resources._legacy • inspect • ipaddress • linecache • locale • operator • pathlib • pickle • pkgutil • platform • re • statistics • tempfile • threading • tokenize • tracemalloc • types • typing • urllib.parse

gc (builtin module)

imports: time

imported by: _posixsubprocess • weakref

genericpath SourceModule

imports: os • stat

imported by: app.py • ntpath • posixpath

getopt SourceModule

imports: gettext • os • sys

imported by: base64 • quopri

gettext SourceModule

imports: builtins • copy • errno • locale • operator • os • re • struct • sys • warnings

imported by: argparse • getopt

glob SourceModule

imports: contextlib • fnmatch • itertools • os • re • stat • sys

imported by: serial.tools.list_ports_common • serial.tools.list_ports_linux • serial.tools.list_ports_posix

grp MissingModule

imported by: pathlib • shutil • subprocess • tarfile

gzip SourceModule

imports: _compression • argparse • builtins • errno • io • os • struct • sys • time • warnings • weakref • zlib

imported by: tarfile

hashlib SourceModule

imports: _blake2 • _hashlib • _md5 • _sha1 • _sha2 • _sha3 • logging

imported by: random • uuid

heapq SourceModule

imports: _heapq

imported by: app.py • collections • queue

importlib Package

imports: _frozen_importlib • _frozen_importlib_external • _imp • importlib • importlib._bootstrap • importlib._bootstrap_external • importlib.machinery • sys • warnings

imported by: _pyi_rth_utils.qt • importlib • importlib._abc • importlib._bootstrap • importlib._bootstrap_external • importlib.abc • importlib.machinery • importlib.metadata • importlib.readers • importlib.resources • importlib.resources._common • importlib.util • inspect • pkgutil • serial

importlib._abc SourceModule

imports: abc • importlib • importlib._bootstrap

imported by: importlib.abc • importlib.util

importlib._bootstrap SourceModule

imports: _frozen_importlib_external • importlib

imported by: importlib • importlib._abc • importlib.machinery • importlib.util

importlib._bootstrap_external SourceModule

imports: _imp • _io • _warnings • importlib • importlib.metadata • importlib.readers • marshal • nt • posix • sys • tokenize • winreg

imported by: importlib • importlib.abc • importlib.machinery • importlib.util • py_compile

importlib.abc SourceModule

imports: _frozen_importlib • _frozen_importlib_external • abc • importlib • importlib._abc • importlib._bootstrap_external • importlib.machinery • importlib.resources • importlib.resources.abc • warnings

imported by: importlib.metadata

importlib.machinery SourceModule

imports: importlib • importlib._bootstrap • importlib._bootstrap_external

imported by: importlib • importlib.abc • inspect • pkgutil • py_compile

importlib.metadata Package

imports: abc • collections • contextlib • csv • email • functools • importlib • importlib.abc • importlib.metadata • importlib.metadata._adapters • importlib.metadata._collections • importlib.metadata._functools • importlib.metadata._itertools • importlib.metadata._meta • inspect • itertools • operator • os • pathlib • posixpath • re • sys • textwrap • typing • warnings • zipfile

imported by: importlib._bootstrap_external • importlib.metadata • importlib.metadata._adapters • importlib.metadata._collections • importlib.metadata._functools • importlib.metadata._itertools • importlib.metadata._meta • importlib.metadata._text

importlib.metadata._adapters SourceModule

imports: email.message • functools • importlib.metadata • importlib.metadata._text • re • textwrap • warnings

imported by: importlib.metadata

importlib.metadata._collections SourceModule

imports: collections • importlib.metadata

imported by: importlib.metadata

importlib.metadata._functools SourceModule

imports: functools • importlib.metadata • types

imported by: importlib.metadata • importlib.metadata._text

importlib.metadata._itertools SourceModule

imports: importlib.metadata • itertools

imported by: importlib.metadata

importlib.metadata._meta SourceModule

imports: importlib.metadata • typing

imported by: importlib.metadata

importlib.metadata._text SourceModule

imports: importlib.metadata • importlib.metadata._functools • re

imported by: importlib.metadata._adapters

importlib.readers SourceModule

imports: importlib • importlib.resources.readers

imported by: importlib._bootstrap_external • zipimport

importlib.resources Package

imports: importlib • importlib.resources • importlib.resources._common • importlib.resources._legacy • importlib.resources.abc

imported by: importlib.abc • importlib.resources • importlib.resources._adapters • importlib.resources._common • importlib.resources._itertools • importlib.resources._legacy • importlib.resources.abc • importlib.resources.readers

importlib.resources._adapters SourceModule

imports: contextlib • importlib.resources • importlib.resources.abc • io

imported by: importlib.resources._common

importlib.resources._common SourceModule

imports: contextlib • functools • importlib • importlib.resources • importlib.resources._adapters • importlib.resources.abc • inspect • itertools • os • pathlib • tempfile • types • typing • warnings

imported by: importlib.resources • importlib.resources._legacy

importlib.resources._itertools SourceModule

imports: importlib.resources

imported by: importlib.resources.readers

importlib.resources._legacy SourceModule

imports: functools • importlib.resources • importlib.resources._common • os • pathlib • types • typing • warnings

imported by: importlib.resources

importlib.resources.abc SourceModule

imports: abc • importlib.resources • io • itertools • os • pathlib • typing

imported by: importlib.abc • importlib.resources • importlib.resources._adapters • importlib.resources._common • importlib.resources.readers

importlib.resources.readers SourceModule

imports: collections • importlib.resources • importlib.resources._itertools • importlib.resources.abc • itertools • operator • pathlib • zipfile

imported by: importlib.readers

importlib.util SourceModule

imports: _imp • importlib • importlib._abc • importlib._bootstrap • importlib._bootstrap_external • sys • threading • types

imported by: pkgutil • py_compile • zipfile

inspect SourceModule

imports: abc • argparse • ast • builtins • collections • collections.abc • dis • enum • functools • importlib • importlib.machinery • itertools • keyword • linecache • operator • os • re • sys • token • tokenize • types • weakref

imported by: ast • dataclasses • importlib.metadata • importlib.resources._common • pkgutil • pyi_rth_inspect.py • typing

io SourceModule

imports: _io • abc

imported by: _compression • app.py • bz2 • csv • dis • email.feedparser • email.generator • email.iterators • email.message • email.parser • encodings.quopri_codec • encodings.uu_codec • gzip • importlib.resources._adapters • importlib.resources.abc • logging • lzma • os • pathlib • pickle • pprint • quopri • serial.serialutil • socket • subprocess • tarfile • tempfile • tokenize • uuid • zipfile • zipfile._path

ipaddress SourceModule

imports: functools • re

imported by: urllib.parse

itertools (builtin module)

imported by: _pydecimal • calendar • collections • dataclasses • glob • importlib.metadata • importlib.metadata._itertools • importlib.resources._common • importlib.resources.abc • importlib.resources.readers • inspect • pickle • platform • random • reprlib • statistics • threading • tokenize • traceback • weakref • zipfile._path

java MissingModule

imported by: platform

json Package

imports: codecs • json.decoder • json.encoder • json.scanner

imported by: experiments • fluorometry • json.decoder • json.encoder • json.scanner • protocol • results_quality • session_store

json.decoder SourceModule

imports: _json • json • json.scanner • re

imported by: _json • json

json.encoder SourceModule

imports: _json • json • re

imported by: json

json.scanner SourceModule

imports: _json • json • re

imported by: json • json.decoder

keyword SourceModule

imported by: app.py • collections • dataclasses • inspect

linecache SourceModule

imports: functools • os • sys • tokenize

imported by: app.py • inspect • traceback • tracemalloc • warnings

locale SourceModule

imports: _collections_abc • _locale • builtins • encodings • encodings.aliases • functools • os • re • sys • warnings

imported by: _pydecimal • _strptime • app.py • calendar • gettext • subprocess

logging Package

imports: atexit • collections.abc • io • os • pickle • re • string • sys • threading • time • traceback • types • warnings • weakref

imported by: hashlib

lzma SourceModule

imports: _compression • _lzma • builtins • io • os

imported by: shutil • tarfile • zipfile

main_window SourceModule

imports: PyQt6.QtCore • PyQt6.QtGui • PyQt6.QtWidgets • __future__ • datetime • display_mirror • experiments • exporter • math • pathlib • protocol • results_quality • serial_client • spectral_plot • sys • telemetry_writer • theme • time • typing • uuid

imported by: app.py

marshal (builtin module)

imported by: importlib._bootstrap_external • pkgutil • zipimport

math (builtin module)

imported by: _pydatetime • _pydecimal • analysis • experiment_validation • fluorometry • fractions • main_window • random • selectors • statistics • urllib.parse

msvcrt (builtin module)

imported by: subprocess

nt (builtin module)

imported by: ctypes • importlib._bootstrap_external • ntpath • os • shutil

ntpath SourceModule

imports: _winapi • genericpath • nt • os • re • stat • sys

imported by: app.py • os • os.path • pathlib

numbers SourceModule

imports: abc

imported by: _pydecimal • fractions • statistics

opcode SourceModule

imports: _opcode

imported by: dis

operator SourceModule

imports: _operator • builtins • functools

imported by: _pydatetime • app.py • collections • copyreg • email._header_value_parser • enum • fractions • gettext • importlib.metadata • importlib.resources.readers • inspect • random • statistics • typing

os SourceModule

imports: _collections_abc • abc • io • nt • ntpath • os.path • posix • posixpath • stat • subprocess • sys • warnings

imported by: PyQt6 • _pyi_rth_utils • _pyi_rth_utils.qt • app.py • argparse • bz2 • contextlib • ctypes • email.utils • fnmatch • genericpath • getopt • gettext • glob • gzip • importlib.metadata • importlib.resources._common • importlib.resources._legacy • importlib.resources.abc • inspect • linecache • locale • logging • lzma • ntpath • os.path • pathlib • pkgutil • platform • posixpath • py_compile • pyi_rth_inspect.py • pyi_rth_pyqt6.py • random • serial • serial.serialposix • serial.tools.list_ports • serial.tools.list_ports_common • serial.tools.list_ports_linux • serial.tools.list_ports_posix • session_store • shutil • socket • subprocess • tarfile • tempfile • threading • uuid • zipfile

os.path AliasNode

imports: ntpath • os

imported by: os • pkgutil • py_compile • serial.tools.list_ports_common • tracemalloc

pathlib SourceModule

imports: _collections_abc • errno • fnmatch • functools • grp • io • ntpath • os • posixpath • pwd • re • stat • sys • urllib.parse • warnings

imported by: experiments • exporter • importlib.metadata • importlib.resources._common • importlib.resources._legacy • importlib.resources.abc • importlib.resources.readers • main_window • results_quality • session_store • zipfile._path

pickle SourceModule

imports: _compat_pickle • _pickle • codecs • copyreg • functools • io • itertools • pprint • re • struct • sys • types

imported by: logging • tracemalloc

pkgutil SourceModule

imports: collections • functools • importlib • importlib.machinery • importlib.util • inspect • marshal • os • os.path • re • sys • types • warnings • zipimport

imported by: PyQt6 • pyi_rth_pkgutil.py

platform SourceModule

imports: 'java.lang' • _winreg • _wmi • collections • functools • itertools • java • os • re • socket • struct • subprocess • sys • vms_lib • winreg

imported by: uuid

posix MissingModule

imports: resource

imported by: importlib._bootstrap_external • os • posixpath • shutil

posixpath SourceModule

imports: genericpath • os • posix • pwd • re • stat • sys

imported by: app.py • fnmatch • importlib.metadata • os • pathlib • zipfile._path

pprint SourceModule

imports: collections • dataclasses • io • re • sys • types

imported by: pickle

protocol SourceModule

imports: __future__ • json • re • typing

imported by: analysis • display_mirror • experiment_validation • experiments • exporter • main_window • results_quality • serial_client • spectral_plot

pwd MissingModule

imported by: pathlib • posixpath • shutil • subprocess • tarfile

py_compile SourceModule

imports: argparse • enum • importlib._bootstrap_external • importlib.machinery • importlib.util • os • os.path • sys • traceback

imported by: zipfile

pyimod02_importers MissingModule

imported by: pyi_rth_pkgutil.py

queue SourceModule

imports: _queue • collections • heapq • threading • time • types

imported by: telemetry_writer

quopri SourceModule

imports: binascii • getopt • io • sys

imported by: email.encoders • email.message • encodings.quopri_codec

random SourceModule

imports: _collections_abc • _random • _sha2 • bisect • hashlib • itertools • math • operator • os • statistics • time • warnings

imported by: email.generator • email.utils • statistics • tempfile • uuid

re Package

imports: _sre • copyreg • enum • functools • re • re._compiler • re._constants • re._parser • warnings

imported by: PyQt6.QtCore • PyQt6.QtGui • PyQt6.QtWidgets • _pydecimal • _sre • _strptime • app.py • argparse • ast • base64 • csv • dataclasses • email._encoded_words • email._header_value_parser • email.feedparser • email.generator • email.header • email.message • email.policy • email.quoprimime • email.utils • encodings.idna • fnmatch • fractions • gettext • glob • importlib.metadata • importlib.metadata._adapters • importlib.metadata._text • inspect • ipaddress • json.decoder • json.encoder • json.scanner • locale • logging • ntpath • pathlib • pickle • pkgutil • platform • posixpath • pprint • protocol • re • re._casefix • re._compiler • re._constants • re._parser • serial.tools.list_ports • serial.tools.list_ports_common • serial.tools.list_ports_windows • sre_compile • sre_constants • sre_parse • string • tarfile • textwrap • tokenize • typing • urllib.parse • warnings • zipfile._path • zipfile._path.glob

re._casefix SourceModule

imports: re

imported by: app.py • re._compiler

re._compiler SourceModule

imports: _sre • re • re._casefix • re._constants • re._parser • sys

imported by: app.py • re • sre_compile

re._constants SourceModule

imports: _sre • re

imported by: app.py • re • re._compiler • re._parser • sre_constants

re._parser SourceModule

imports: re • re._constants • unicodedata • warnings

imported by: app.py • re • re._compiler • sre_parse

reprlib SourceModule

imports: _thread • builtins • itertools

imported by: app.py • collections • functools

resource MissingModule

imported by: posix

results_quality SourceModule

imports: PyQt6.QtCore • PyQt6.QtWidgets • analysis • copy • csv • datetime • fluorometry • json • pathlib • protocol

imported by: main_window

select C:\Users\47470482\AppData\Roaming\uv\python\cpython-3.12-windows-x86_64-none\DLLs\select.pyd

imported by: selectors • serial.serialposix • subprocess

selectors SourceModule

imports: abc • collections • collections.abc • math • select • sys

imported by: socket • subprocess

serial Package

imports: __future__ • importlib • os • serial.serialcli • serial.serialjava • serial.serialposix • serial.serialutil • serial.serialwin32 • serial.win32 • sys

imported by: serial.serialcli • serial.serialjava • serial.serialposix • serial.serialutil • serial.serialwin32 • serial.tools • serial.tools.list_ports_posix • serial.tools.list_ports_windows • serial.win32 • serial_client

serial.serialcli SourceModule

imports: 'System.IO' • System • __future__ • serial • serial.serialutil

imported by: serial

serial.serialjava SourceModule

imports: __future__ • serial • serial.serialutil

imported by: serial

serial.serialposix SourceModule

imports: __future__ • array • errno • fcntl • os • select • serial • serial.serialutil • struct • sys • termios • warnings

imported by: serial

serial.serialutil SourceModule

imports: __future__ • array • io • serial • sys • time

imported by: serial • serial.serialcli • serial.serialjava • serial.serialposix • serial.serialwin32

serial.serialwin32 SourceModule

imports: __future__ • ctypes • serial • serial.serialutil • serial.win32 • time

imported by: serial

serial.tools Package

imports: serial • serial.tools.list_ports • serial.tools.list_ports_common

imported by: serial.tools.list_ports • serial.tools.list_ports_common • serial.tools.list_ports_linux • serial.tools.list_ports_osx • serial.tools.list_ports_posix • serial.tools.list_ports_windows • serial_client

serial.tools.list_ports SourceModule

imports: __future__ • argparse • os • re • serial.tools • serial.tools.list_ports_posix • serial.tools.list_ports_windows • sys

imported by: serial.tools • serial_client

serial.tools.list_ports_common SourceModule

imports: __future__ • glob • os • os.path • re • serial.tools

imported by: serial.tools • serial.tools.list_ports_linux • serial.tools.list_ports_osx • serial.tools.list_ports_posix • serial.tools.list_ports_windows

serial.tools.list_ports_linux SourceModule

imports: __future__ • glob • os • serial.tools • serial.tools.list_ports_common

imported by: serial.tools.list_ports_posix

serial.tools.list_ports_osx SourceModule

imports: __future__ • ctypes • serial.tools • serial.tools.list_ports_common

imported by: serial.tools.list_ports_posix

serial.tools.list_ports_posix SourceModule

imports: __future__ • glob • os • serial • serial.tools • serial.tools.list_ports_common • serial.tools.list_ports_linux • serial.tools.list_ports_osx • sys

imported by: serial.tools.list_ports

serial.tools.list_ports_windows SourceModule

imports: __future__ • ctypes • ctypes.wintypes • re • serial • serial.tools • serial.tools.list_ports_common • serial.win32

imported by: serial.tools.list_ports

serial.win32 SourceModule

imports: __future__ • ctypes • ctypes.wintypes • serial

imported by: serial • serial.serialwin32 • serial.tools.list_ports_windows

serial_client SourceModule

imports: PyQt6.QtCore • __future__ • protocol • serial • serial.tools • serial.tools.list_ports • typing

imported by: main_window

session_store SourceModule

imports: json • os • pathlib • tempfile

imported by: experiments

shutil SourceModule

imports: _winapi • bz2 • collections • errno • fnmatch • grp • lzma • nt • os • posix • pwd • stat • sys • tarfile • warnings • zipfile • zlib

imported by: argparse • exporter • tarfile • tempfile • uuid • zipfile

signal SourceModule

imports: _signal • enum

imported by: subprocess

socket SourceModule

imports: _socket • array • enum • errno • io • os • selectors • sys

imported by: email.utils • platform • uuid

spectral_plot SourceModule

imports: PyQt6.QtCore • PyQt6.QtGui • PyQt6.QtWidgets • __future__ • protocol • time

imported by: main_window

sre_compile SourceModule

imports: re • re._compiler • warnings

imported by: app.py

sre_constants SourceModule

imports: re • re._constants • warnings

imported by: app.py

sre_parse SourceModule

imports: re • re._parser • warnings

imported by: app.py

stat SourceModule

imports: _stat

imported by: app.py • genericpath • glob • ntpath • os • pathlib • posixpath • shutil • tarfile • zipfile

statistics SourceModule

imports: _statistics • bisect • collections • decimal • fractions • functools • itertools • math • numbers • operator • random • sys

imported by: analysis • fluorometry • random

string SourceModule

imports: _string • collections • re

imported by: email._encoded_words • email._header_value_parser • email.quoprimime • logging

stringprep SourceModule

imports: unicodedata

imported by: encodings.idna

struct SourceModule

imports: _struct

imported by: base64 • ctypes • gettext • gzip • pickle • platform • serial.serialposix • tarfile • zipfile

subprocess SourceModule

imports: _posixsubprocess • _winapi • builtins • contextlib • errno • fcntl • grp • io • locale • msvcrt • os • pwd • select • selectors • signal • sys • threading • time • types • warnings

imported by: os • platform • uuid

sys (builtin module)

imported by: PyQt6 • _collections_abc • _compression • _pydatetime • _pydecimal • _pyi_rth_utils • app.py • argparse • ast • base64 • calendar • codecs • collections • contextlib • ctypes • ctypes._endian • dataclasses • dis • email._header_value_parser • email.generator • email.iterators • email.policy • encodings • encodings.rot_13 • encodings.utf_16 • encodings.utf_32 • enum • fractions • getopt • gettext • glob • gzip • importlib • importlib._bootstrap_external • importlib.metadata • importlib.util • inspect • linecache • locale • logging • main_window • ntpath • os • pathlib • pickle • pkgutil • platform • posixpath • pprint • py_compile • pyi_rth_inspect.py • pyi_rth_pyqt6.py • quopri • re._compiler • selectors • serial • serial.serialposix • serial.serialutil • serial.tools.list_ports • serial.tools.list_ports_posix • shutil • socket • statistics • subprocess • tarfile • tempfile • threading • tokenize • traceback • types • typing • uuid • warnings • weakref • zipfile • zipimport

tarfile SourceModule

imports: argparse • builtins • bz2 • copy • grp • gzip • io • lzma • os • pwd • re • shutil • stat • struct • sys • time • warnings • zlib

imported by: shutil

telemetry_writer SourceModule

imports: PyQt6.QtCore • __future__ • dataclasses • datetime • exporter • queue • threading • typing

imported by: main_window

tempfile SourceModule

imports: _thread • errno • functools • io • os • random • shutil • sys • types • warnings • weakref

imported by: exporter • importlib.resources._common • session_store

termios MissingModule

imported by: serial.serialposix

textwrap SourceModule

imports: re

imported by: argparse • importlib.metadata • importlib.metadata._adapters • traceback

theme SourceModule

imports: PyQt6.QtGui • PyQt6.QtWidgets

imported by: main_window

threading SourceModule

imports: _collections • _thread • _threading_local • _weakrefset • collections • functools • itertools • os • sys • time • traceback • warnings

imported by: _threading_local • importlib.util • logging • queue • subprocess • telemetry_writer • zipfile

time (builtin module)

imports: _strptime

imported by: _datetime • _pydatetime • _strptime • datetime • email._parseaddr • email.generator • email.utils • gc • gzip • logging • main_window • queue • random • serial.serialutil • serial.serialwin32 • spectral_plot • subprocess • tarfile • threading • uuid • zipfile • zipimport

token SourceModule

imported by: inspect • tokenize

tokenize SourceModule

imports: _tokenize • argparse • builtins • codecs • collections • functools • io • itertools • re • sys • token

imported by: importlib._bootstrap_external • inspect • linecache

traceback SourceModule

imports: ast • collections.abc • contextlib • itertools • linecache • sys • textwrap • unicodedata

imported by: app.py • logging • py_compile • threading • warnings

tracemalloc SourceModule

imports: _tracemalloc • collections.abc • fnmatch • functools • linecache • os.path • pickle

imported by: warnings

types SourceModule

imports: _collections_abc • functools • sys

imported by: _weakrefset • app.py • contextlib • copy • csv • ctypes • dataclasses • dis • email.headerregistry • enum • functools • importlib.metadata._functools • importlib.resources._common • importlib.resources._legacy • importlib.util • inspect • logging • pickle • pkgutil • pprint • queue • subprocess • tempfile • typing • urllib.parse

typing SourceModule

imports: _typing • abc • collections • collections.abc • contextlib • copyreg • functools • inspect • operator • re • sys • types • warnings

imported by: PyQt6.QtCore • PyQt6.QtGui • PyQt6.QtWidgets • PyQt6.sip • exporter • functools • importlib.metadata • importlib.metadata._meta • importlib.resources._common • importlib.resources._legacy • importlib.resources.abc • main_window • protocol • serial_client • telemetry_writer

unicodedata C:\Users\47470482\AppData\Roaming\uv\python\cpython-3.12-windows-x86_64-none\DLLs\unicodedata.pyd

imported by: encodings.idna • re._parser • stringprep • traceback • urllib.parse

urllib Package

imported by: email._header_value_parser • urllib.parse

urllib.parse SourceModule

imports: collections • functools • ipaddress • math • re • types • unicodedata • urllib • warnings

imported by: email.utils • pathlib

uuid SourceModule

imports: _uuid • argparse • enum • hashlib • io • os • platform • random • shutil • socket • subprocess • sys • time

imported by: analysis • experiments • fluorometry • main_window

vms_lib MissingModule

imported by: platform

warnings SourceModule

imports: _warnings • builtins • linecache • re • sys • traceback • tracemalloc

imported by: PyQt6.QtCore • PyQt6.QtGui • PyQt6.QtWidgets • _collections_abc • _pydatetime • app.py • argparse • ast • calendar • email.utils • enum • gettext • gzip • importlib • importlib.abc • importlib.metadata • importlib.metadata._adapters • importlib.resources._common • importlib.resources._legacy • locale • logging • os • pathlib • pkgutil • random • re • re._parser • serial.serialposix • shutil • sre_compile • sre_constants • sre_parse • subprocess • tarfile • tempfile • threading • typing • urllib.parse • zipfile

weakref SourceModule

imports: _collections_abc • _weakref • _weakrefset • atexit • copy • gc • itertools • sys

imported by: _threading_local • app.py • copy • functools • gzip • inspect • logging • tempfile

winreg (builtin module)

imported by: importlib._bootstrap_external • platform

zipfile Package

imports: argparse • binascii • bz2 • importlib.util • io • lzma • os • py_compile • shutil • stat • struct • sys • threading • time • warnings • zipfile._path • zlib

imported by: importlib.metadata • importlib.resources.readers • pyi_rth_inspect.py • shutil • zipfile._path

zipfile._path Package

imports: contextlib • io • itertools • pathlib • posixpath • re • zipfile • zipfile._path.glob

imported by: zipfile • zipfile._path.glob

zipfile._path.glob SourceModule

imports: re • zipfile._path

imported by: zipfile._path

zipimport SourceModule

imports: _frozen_importlib • _frozen_importlib_external • _imp • _io • _warnings • importlib.readers • marshal • sys • time • zlib

imported by: pkgutil

zlib (builtin module)

imported by: encodings.zlib_codec • gzip • shutil • tarfile • zipfile • zipimport

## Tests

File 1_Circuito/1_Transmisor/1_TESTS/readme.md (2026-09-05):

# Pruebas de circuitos y códigos previo a la implementación del prototipo del fluorimetro

Las pruebas son:

- **1_CORRIENTE_DELTA_SIGMA**: Que es el circuito para implementar el control de corriente lineal del led por medio de una DAC delta-sigma que usa el pin 11 del arduino mega, pin que usa  PWM para simular una DAC. Se le agrega un filtro RC para pasar de PWM a valor analógico.
- **2_DAC_LED_UNO_R4**: Busca usar el DAC nativo del arduino uno R4 y aprovechar su puerto QWIIC nativo para usar el sensor de color.
- **3_TEST_KICAD**: Se creo una shield para arduino mega que incorpora una pantalla LCD NOKIA.

## Test LCD Nokia
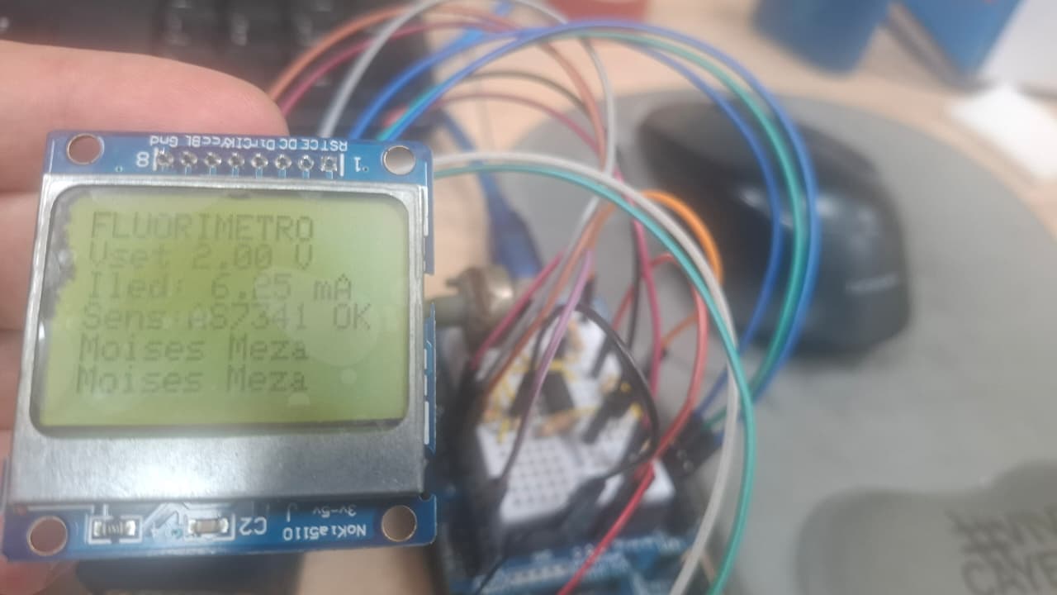
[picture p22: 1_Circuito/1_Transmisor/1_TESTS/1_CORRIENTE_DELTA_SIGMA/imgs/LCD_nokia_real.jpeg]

## Test PCB
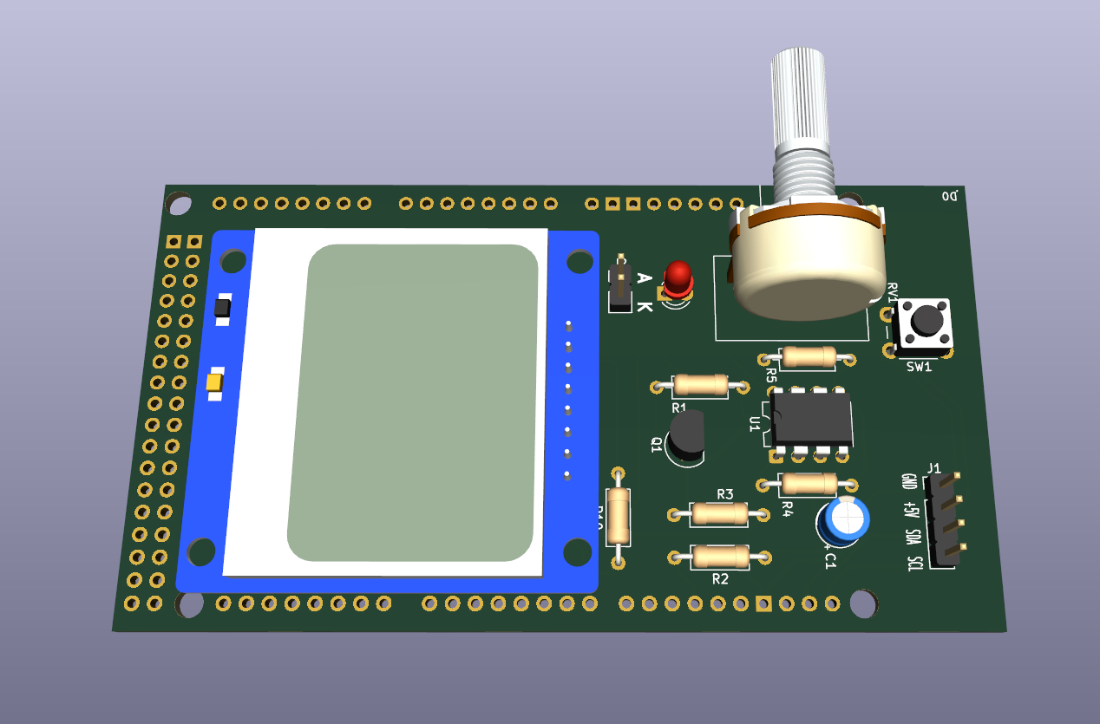
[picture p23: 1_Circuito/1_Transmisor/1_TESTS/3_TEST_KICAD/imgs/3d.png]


## Código de LCD Nokia
Las Librerias deben ser instaladas usando el entorno de Arduino IDE.
- Adafruit_GFX
- Adafruit_PCD8544

Código:

```c++
#include <SPI.h>
#include <Adafruit_GFX.h>
#include <Adafruit_PCD8544.h>

// Definición de pines para Arduino Mega (Configuración por Software SPI)
// Pin 13 - CLK (conectado mediante resistencia de 10k a la pantalla)
// Pin 11 - DIN (conectado mediante resistencia de 10k a la pantalla)
const int pin_DC  = 5;
const int pin_CE  = 4;
const int pin_RST = 3;

// Inicializamos la pantalla con el constructor de Software SPI
Adafruit_PCD8544 display = Adafruit_PCD8544(52, 51, pin_DC, pin_CE, pin_RST);

void setup() {
  Serial.begin(115200);
  
  // Inicializar la pantalla con el contraste típico (ajustar entre 50 y 60 si no se ve)
  display.begin();
  display.setContrast(55); 
  delay(1000);
  display.clearDisplay();   // Borra el buffer interno
  display.setRotation(2);
  display.display();        // Muestra la pantalla en blanco inicial
  delay(1000);
}

void loop() {
  display.clearDisplay();
  
  // Configuración de texto
  display.setTextSize(1);      // Tamaño de fuente pequeño (ideal para esta pantalla)
  display.setTextColor(BLACK); // Texto negro sobre fondo claro
  
  // Simulación de interfaz para tu Fluorímetro
  display.setCursor(0,0);
  display.println("FLUORIMETRO");
  
  display.setCursor(0,8);
  display.print("Vset 2.00 V"); // Simulación del voltaje seteado [cite: 422]
  
  display.setCursor(0,16);
  display.print("Iled: 6.25 mA"); // Simulación de la corriente calculada [cite: 376]
  
  display.setCursor(0,24);
  display.print("Sens:AS7341 OK"); // Estado de tu nuevo sensor [cite: 547]
  
  display.setCursor(0,32);
  display.print("Moises Meza");

  display.setCursor(0,40);
  display.print("Moises Meza");
  // Enviamos los datos del buffer directamente a la pantalla física
  display.display();
  
  delay(2000);
}
```

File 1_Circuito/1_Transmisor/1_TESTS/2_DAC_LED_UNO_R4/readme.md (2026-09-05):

# Componentes
|Componente| Descripción|Pines|
|:---:|:--:|:---:|
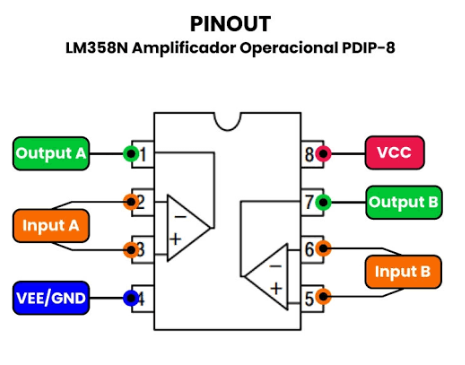
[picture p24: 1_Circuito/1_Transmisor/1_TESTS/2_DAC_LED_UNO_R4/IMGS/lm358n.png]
|LM358N|No es un Op-Amp Rail-to-Rail. Su límite máximo real se queda unos $1.5\text{ V}$ por debajo del riel positivo (es decir, máximo entregará cerca de $3.5\text{ V}$). ||

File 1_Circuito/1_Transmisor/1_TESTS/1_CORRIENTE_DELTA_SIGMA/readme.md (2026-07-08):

# Pruebas del circuito control de corriente

## Circuito original
El circuito fue adaptado del diseño original de IORODEO.

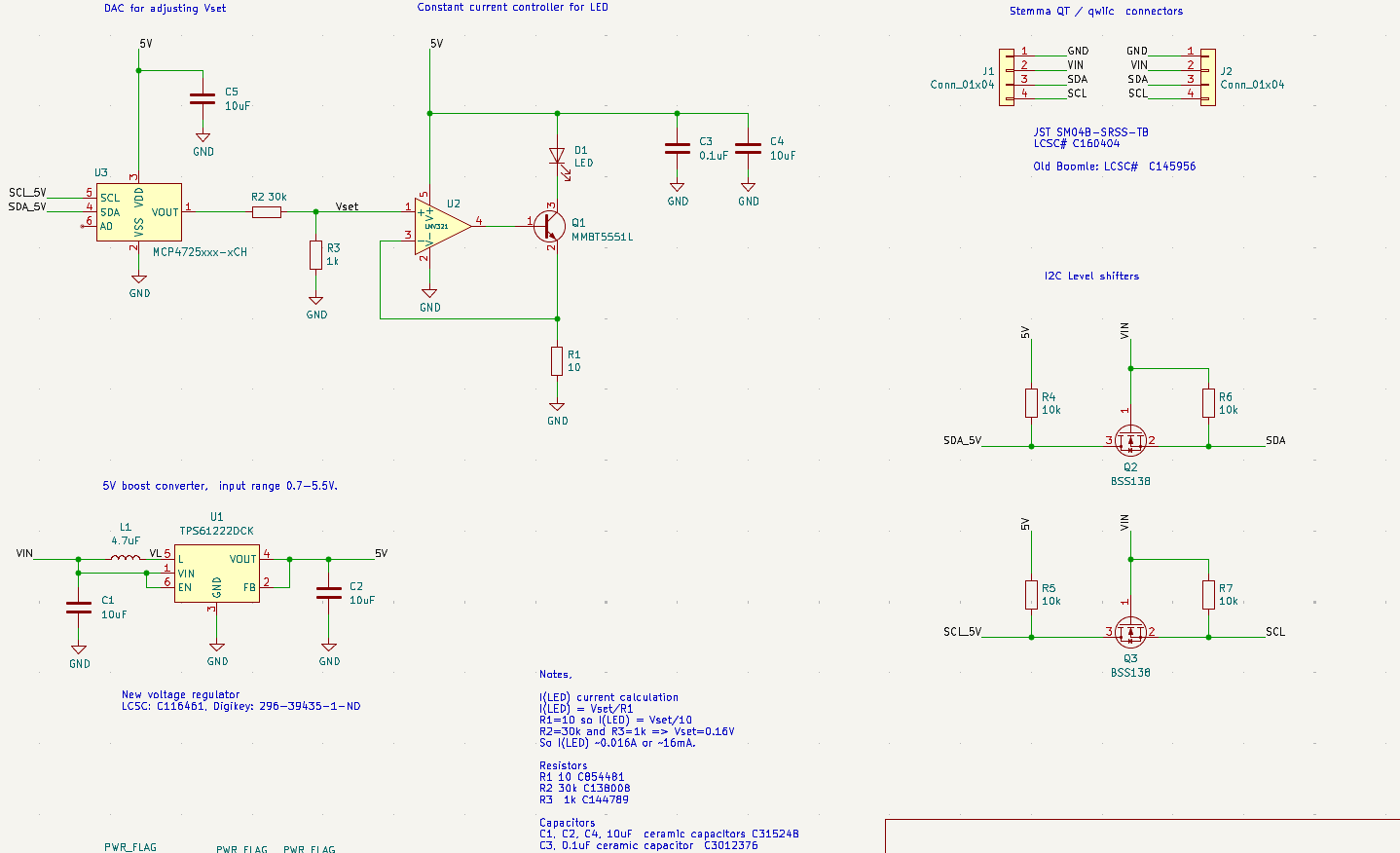
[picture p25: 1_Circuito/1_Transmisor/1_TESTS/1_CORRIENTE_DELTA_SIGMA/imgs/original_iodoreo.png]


## Circuito adaptado
EL circuito original original esta pensado en un microcontrolador de 3.3v por lo que requeria etapas para elevar la tensión de 3.3v a 5v. En ese sentido se optó por probar la tarjeta Arduino Mega que funciona a 5 v. 
Una parte relevante del circuito es setear la tensión de referencia que servirá para controlar la corriente del led (0mA-16mA), para ello se requiere un DAC para cambiar la tensión de salida que servirá para cambiar la intensidad del LED. En ese sentido el arduino Mega no cuenta con un DAC nativo por lo que se uso la configuración de DAC delta-sigma que emula una DAC usando PWM, para ello adicionalmente se debe usar un filtro pasa bajos a la salida del PWM. El arduino MEga usó su Timer 1 con el pin 11 para generar el DAC delta-sigma.

## Pruebas en simulación
Se uso el softtware SimulIDE para la conexión del circuito.

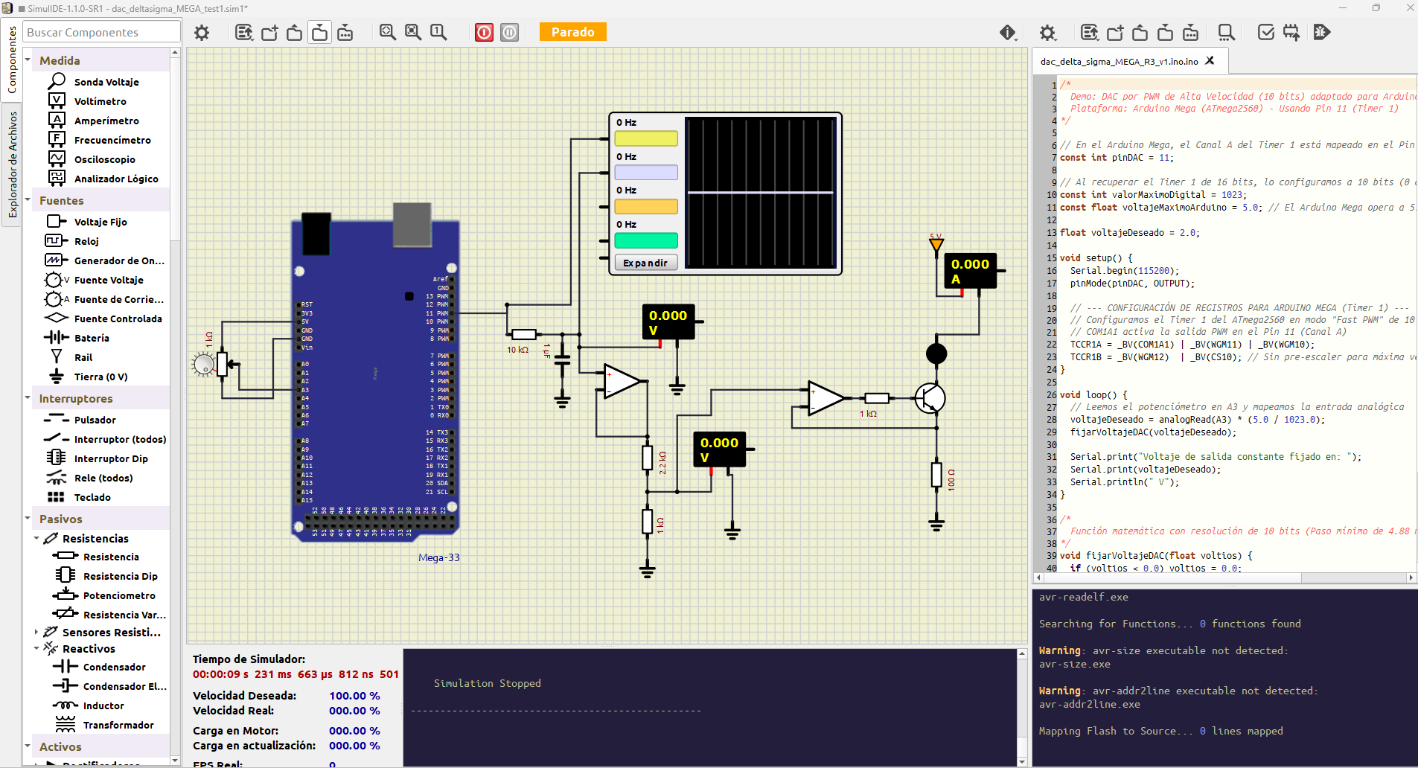
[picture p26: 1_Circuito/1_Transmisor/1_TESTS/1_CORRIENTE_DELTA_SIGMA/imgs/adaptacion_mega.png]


### Partes del circuito

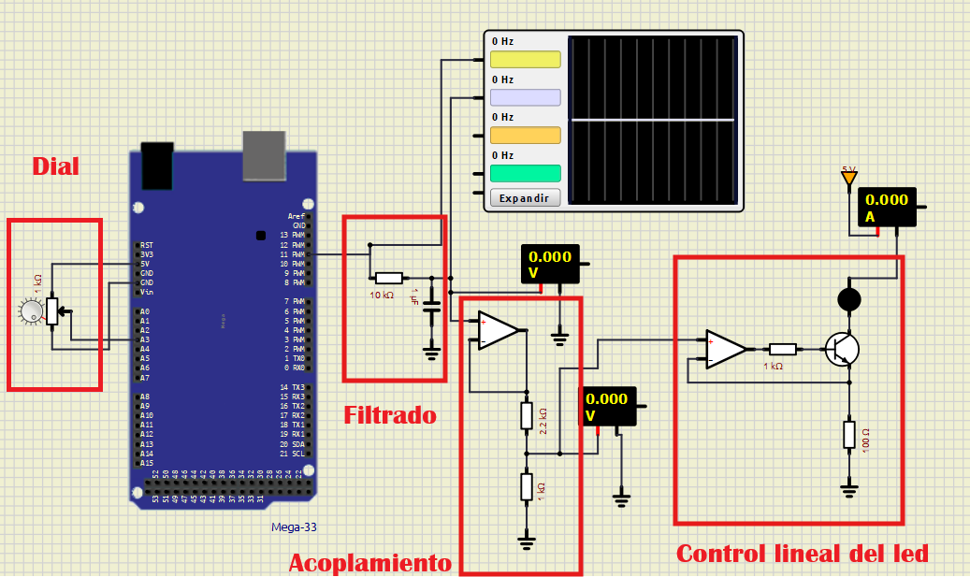
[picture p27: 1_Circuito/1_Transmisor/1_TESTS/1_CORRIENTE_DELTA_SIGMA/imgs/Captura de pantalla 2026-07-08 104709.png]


Control del led
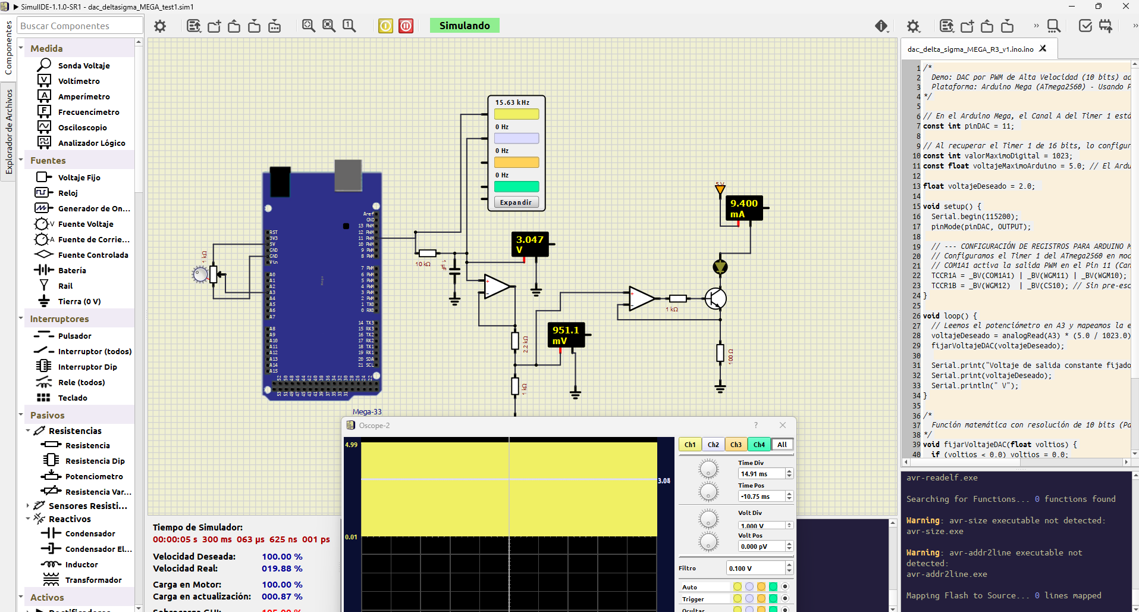
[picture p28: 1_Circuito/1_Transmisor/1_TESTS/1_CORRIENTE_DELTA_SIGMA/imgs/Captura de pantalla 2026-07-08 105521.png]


DAC delta-sigma
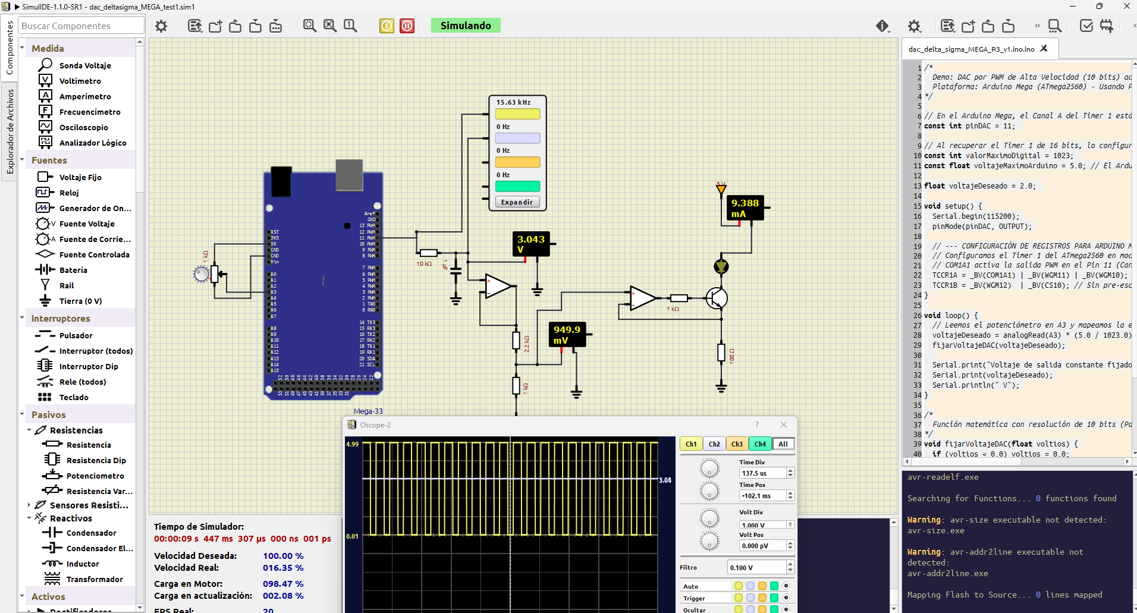
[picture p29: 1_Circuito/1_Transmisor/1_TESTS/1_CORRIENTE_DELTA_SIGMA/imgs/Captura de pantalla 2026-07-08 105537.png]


EL código del Mega fue este:
```c++
/*
  Demo: DAC por PWM de Alta Velocidad (10 bits) adaptado para Arduino Mega
  Plataforma: Arduino Mega (ATmega2560) - Usando Pin 11 (Timer 1)
*/

// En el Arduino Mega, el Canal A del Timer 1 está mapeado en el Pin 11
const int pinDAC = 11; 

// Al recuperar el Timer 1 de 16 bits, lo configuramos a 10 bits (0 a 1023)
const int valorMaximoDigital = 1023; 
const float voltajeMaximoArduino = 5.0; // El Arduino Mega opera a 5.0V

float voltajeDeseado = 2.0; 

void setup() {
  Serial.begin(115200);
  pinMode(pinDAC, OUTPUT);

  // --- CONFIGURACIÓN DE REGISTROS PARA ARDUINO MEGA (Timer 1) ---
  // Configuramos el Timer 1 del ATmega2560 en modo "Fast PWM" de 10 bits (Frecuencia ~15.6 kHz)
  // COM1A1 activa la salida PWM en el Pin 11 (Canal A)
  TCCR1A = _BV(COM1A1) | _BV(WGM11) | _BV(WGM10);
  TCCR1B = _BV(WGM12)  | _BV(CS10); // Sin pre-escaler para máxima velocidad de conmutación
}

void loop() {
  // Leemos el potenciómetro en A3 y mapeamos la entrada analógica
  voltajeDeseado = analogRead(A3) * (5.0 / 1023.0);
  fijarVoltajeDAC(voltajeDeseado);
  
  Serial.print("Voltaje de salida constante fijado en: ");
  Serial.print(voltajeDeseado);
  Serial.println(" V");
}

/*
  Función matemática con resolución de 10 bits (Paso mínimo de 4.88 mV)
*/
void fijarVoltajeDAC(float voltios) {
  if (voltios < 0.0) voltios = 0.0;
  if (voltios > voltajeMaximoArduino) voltios = voltajeMaximoArduino;

  // Regla de tres directa adaptada a 5V y resolución de 1023:
  int valorPWM = (voltios * valorMaximoDigital) / voltajeMaximoArduino;

  // Actualizamos directamente el registro de comparación del Timer 1 (Canal A -> Pin 11)
  OCR1A = valorPWM; 
}
```
# Circuito implementado real

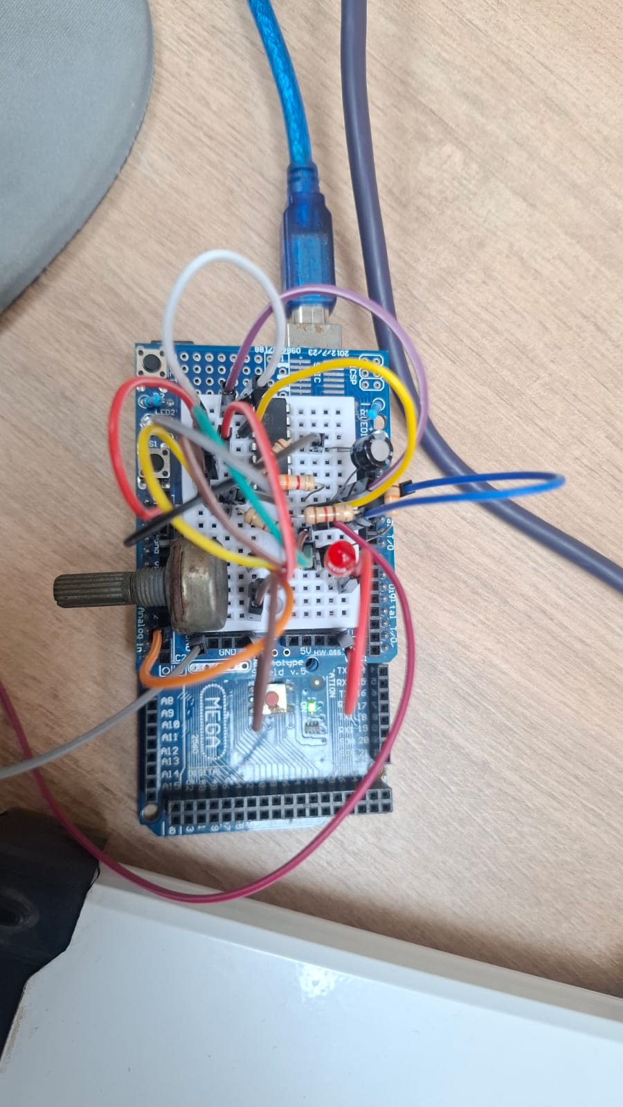
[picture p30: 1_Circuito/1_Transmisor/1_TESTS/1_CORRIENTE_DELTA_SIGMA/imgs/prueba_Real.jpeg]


Se uso el LM324N como OPAMP principal, es un opamp que no es rail-to-rail, es decir no puede llegar ni a 0v  tampoco a 5v, se queda en valores muy cercanos a estos.

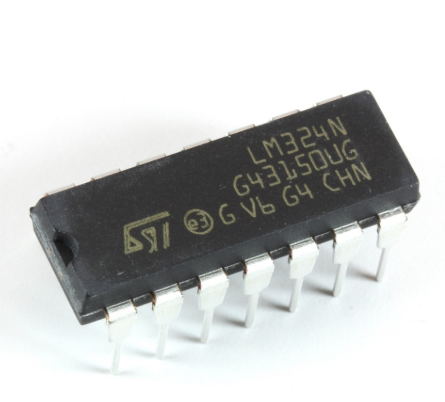
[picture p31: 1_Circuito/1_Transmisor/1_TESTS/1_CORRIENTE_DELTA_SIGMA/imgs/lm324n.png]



### Filtrado
se usaron para el filtro RC:
- Resistencia: 120 ohms
- Capacitor electrolítico:  100uf

### Vset del OPAMP
- R1: 3.3K ohm
- R2: 1K ohm

### Transistor BJT

|BJT|PINOUT|
|:---:|:---:|
|2N2222||

### Pruebas en implementación real del DAC delta-sigma
Led 1v5
Led 1v5

Led 3v2
Led 3v2

Led 4v56
Led 4v56

### Videos de prueba

* [video control led mega](./imgs/test_control_led_mega_v1.mp4)
* [video osciloscopio](./imgs/test_led_mega_v1.mp4)
* [Video simulación](./imgs/simulide_test_led.mp4)

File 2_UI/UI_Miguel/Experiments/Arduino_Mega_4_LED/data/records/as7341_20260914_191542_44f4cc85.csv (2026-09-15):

received_at | sequence | millis | gain | integration_time | pwm_percent | pwm_raw | page | 415 | 445 | 480 | 515 | 555 | 590 | 630 | 680 | nir | clear
2026-09-15T00:15:42.915046+00:00 | 741 | 535980 | 16x | 300ms | 15 | 38 | 0 | 399 | 185 | 2085 | 21882 | 6461 | 993 | 650 | 557 | 691 | 22030
2026-09-15T00:15:43.635001+00:00 | 742 | 536702 | 16x | 300ms | 15 | 38 | 0 | 399 | 185 | 2085 | 21882 | 6461 | 993 | 650 | 557 | 691 | 22030
2026-09-15T00:15:44.363257+00:00 | 743 | 537427 | 16x | 300ms | 15 | 38 | 0 | 399 | 185 | 2085 | 21883 | 6461 | 993 | 650 | 557 | 691 | 22031
2026-09-15T00:15:45.082473+00:00 | 744 | 538152 | 16x | 300ms | 15 | 38 | 1 | 399 | 185 | 2085 | 21882 | 6461 | 993 | 650 | 557 | 691 | 22030
2026-09-15T00:15:45.802971+00:00 | 745 | 538875 | 16x | 300ms | 15 | 38 | 1 | 399 | 185 | 2085 | 21881 | 6460 | 993 | 650 | 557 | 691 | 22030
2026-09-15T00:15:46.523459+00:00 | 746 | 539596 | 16x | 300ms | 15 | 38 | 1 | 399 | 185 | 2085 | 21880 | 6459 | 993 | 650 | 557 | 691 | 22025
2026-09-15T00:15:47.251730+00:00 | 747 | 540319 | 16x | 300ms | 15 | 38 | 1 | 399 | 185 | 2085 | 21878 | 6459 | 993 | 650 | 557 | 691 | 22026
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

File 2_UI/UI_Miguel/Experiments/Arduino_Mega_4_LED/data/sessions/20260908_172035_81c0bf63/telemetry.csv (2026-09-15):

received_at | sequence | millis | gain | integration_time | page | 415 | 445 | 480 | 515 | 555 | 590 | 630 | 680 | nir | clear
2026-09-08T22:26:50.319878+00:00 | 1 | 355 | 128x | 100ms | 0 | 6 | 14 | 18 | 24 | 6 | 14 | 18 | 24 | 23 | 117
2026-09-08T22:26:50.669815+00:00 | 2 | 709 | 128x | 100ms | 0 | 6 | 14 | 18 | 24 | 6 | 14 | 18 | 24 | 23 | 117
2026-09-08T22:26:51.045951+00:00 | 3 | 1063 | 128x | 100ms | 0 | 6 | 14 | 18 | 24 | 6 | 14 | 18 | 24 | 23 | 117
2026-09-08T22:26:51.396293+00:00 | 4 | 1419 | 128x | 100ms | 0 | 6 | 14 | 18 | 24 | 6 | 14 | 18 | 24 | 23 | 117
2026-09-08T22:26:51.745920+00:00 | 5 | 1773 | 128x | 100ms | 0 | 6 | 14 | 18 | 24 | 6 | 14 | 18 | 24 | 23 | 116
2026-09-08T22:26:52.094827+00:00 | 6 | 2127 | 128x | 100ms | 0 | 6 | 14 | 18 | 24 | 6 | 14 | 18 | 24 | 23 | 117
2026-09-08T22:26:52.445872+00:00 | 7 | 2482 | 128x | 100ms | 0 | 6 | 14 | 18 | 24 | 6 | 14 | 18 | 24 | 22 | 116
2026-09-08T22:26:52.820282+00:00 | 8 | 2836 | 128x | 100ms | 0 | 6 | 14 | 18 | 24 | 6 | 14 | 18 | 24 | 22 | 115
2026-09-08T22:26:53.171103+00:00 | 9 | 3190 | 128x | 100ms | 1 | 6 | 14 | 18 | 24 | 6 | 14 | 18 | 24 | 22 | 115
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

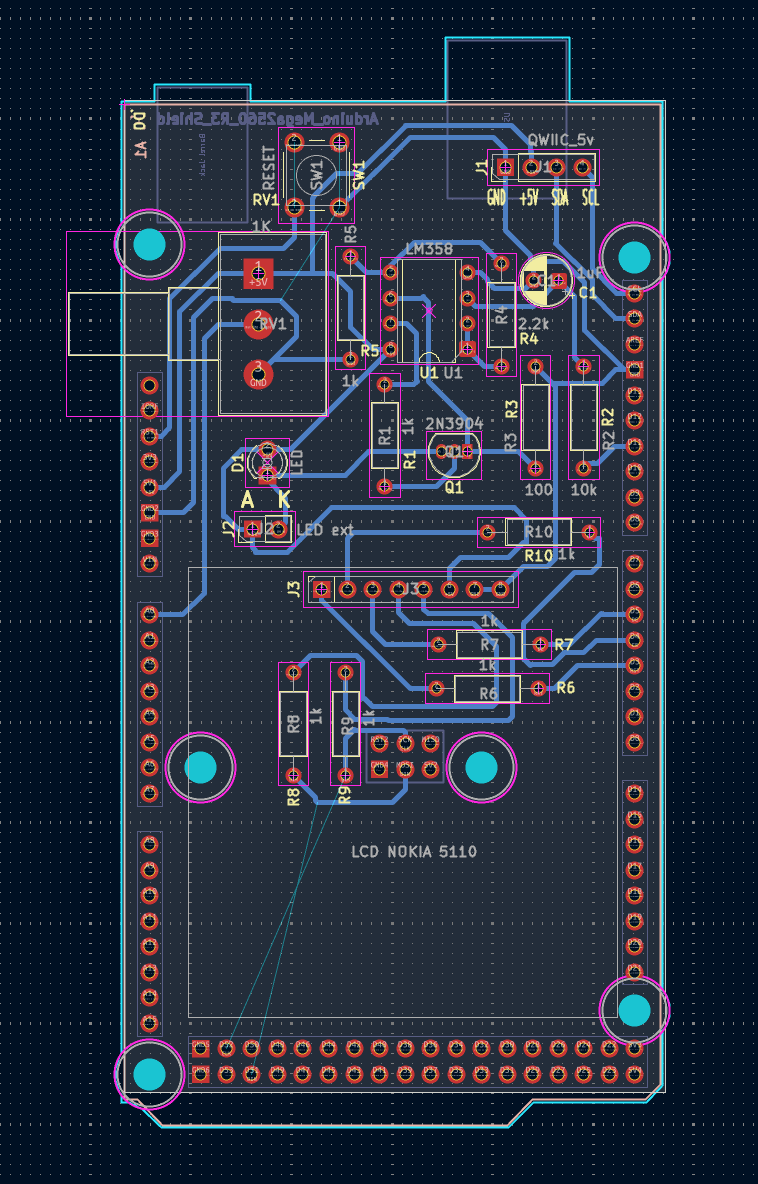
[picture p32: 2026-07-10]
1_Circuito/1_Transmisor/1_TESTS/3_TEST_KICAD/imgs/Screenshot 2026-07-09 203715.png

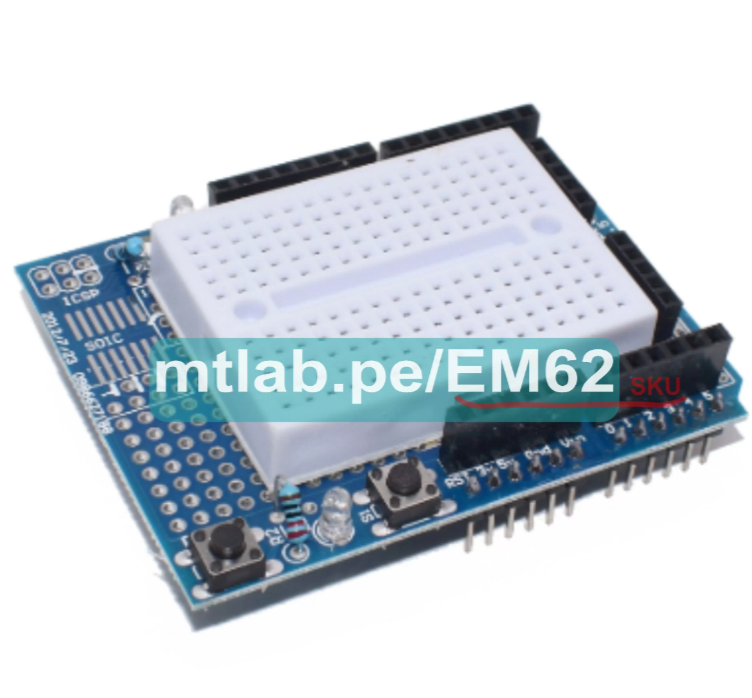
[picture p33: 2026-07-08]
1_Circuito/1_Transmisor/1_TESTS/1_CORRIENTE_DELTA_SIGMA/imgs/breadboard.png

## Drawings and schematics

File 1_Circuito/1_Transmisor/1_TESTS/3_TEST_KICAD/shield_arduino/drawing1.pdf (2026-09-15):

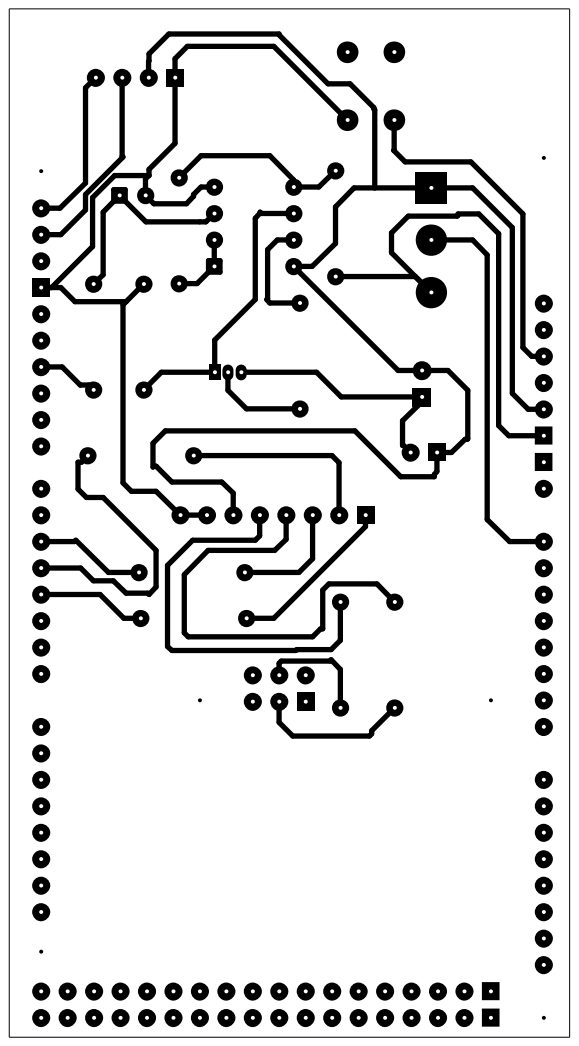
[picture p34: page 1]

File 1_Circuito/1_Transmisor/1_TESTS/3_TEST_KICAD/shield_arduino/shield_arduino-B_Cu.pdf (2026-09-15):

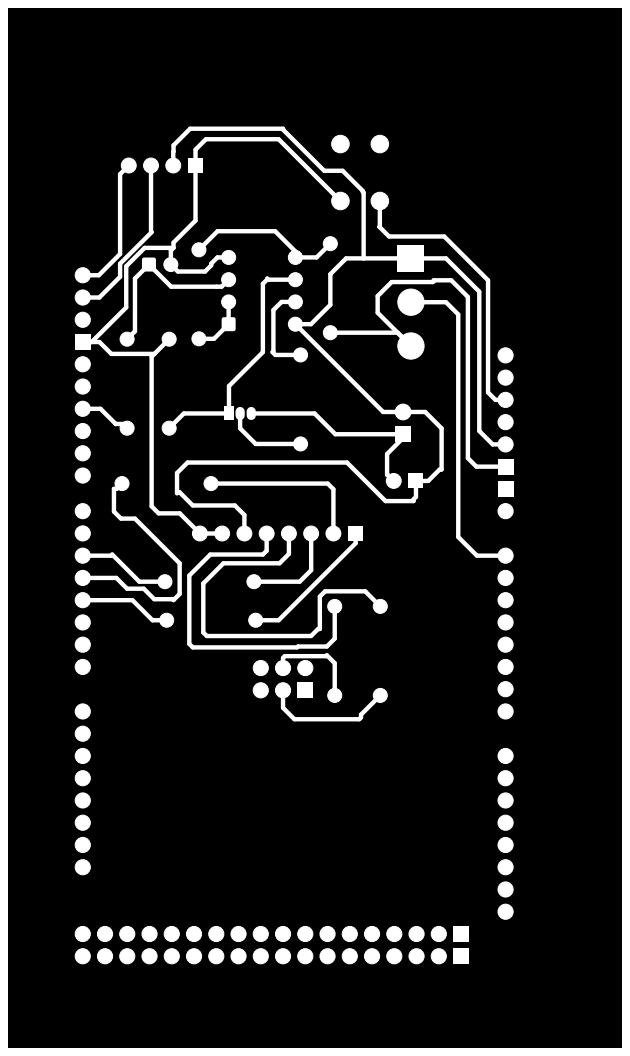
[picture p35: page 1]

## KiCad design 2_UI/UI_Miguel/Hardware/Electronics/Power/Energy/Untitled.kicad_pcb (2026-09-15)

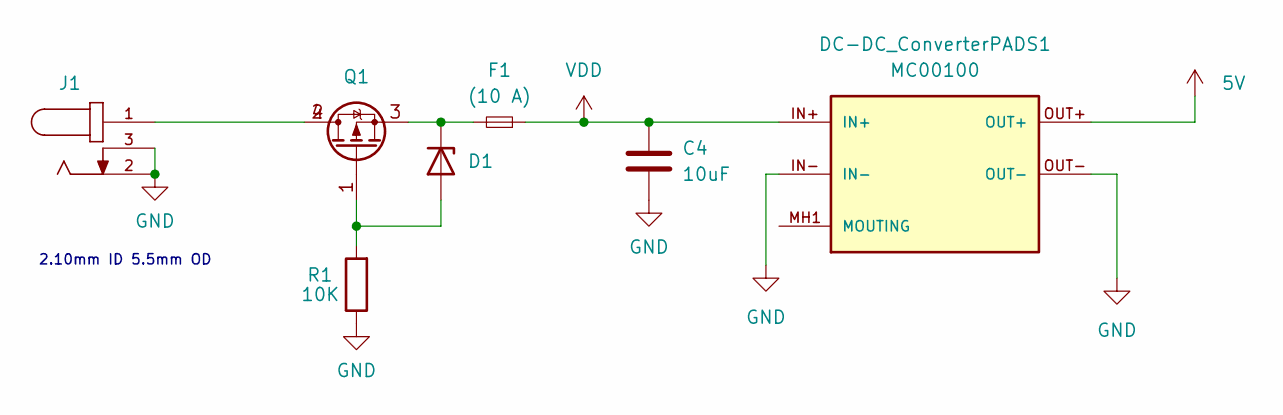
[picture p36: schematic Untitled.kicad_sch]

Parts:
C4: 10uF; C_0805_2012Metric
D1: D_Zener; MMSZ4700T1G
DC-DC_ConverterPADS1: MC00100; CONV_MC00100; PARTREV NA
F1: (10 A); 0154010.DRL; Part 0154010.DRL
J1: PJ-002A
Q1: DMP6023LE-13
R1: 10K; R_0805_2012Metric

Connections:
5V: DC-DC_ConverterPADS1.OUT+
GND: C4.2, DC-DC_ConverterPADS1.IN-, DC-DC_ConverterPADS1.OUT-, J1.2, J1.3, R1.1
unnamed: D1.2 (A), Q1.1, R1.2
unnamed: D1.1 (K), F1.2, Q1.3
unnamed: DC-DC_ConverterPADS1.MH1 (MOUTING), DC-DC_ConverterPADS1.MH2 (MOUTING)
unnamed: J1.1, Q1.2, Q1.4
VDD: C4.1, DC-DC_ConverterPADS1.IN+, F1.1

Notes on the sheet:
2.10mm ID 5.5mm OD

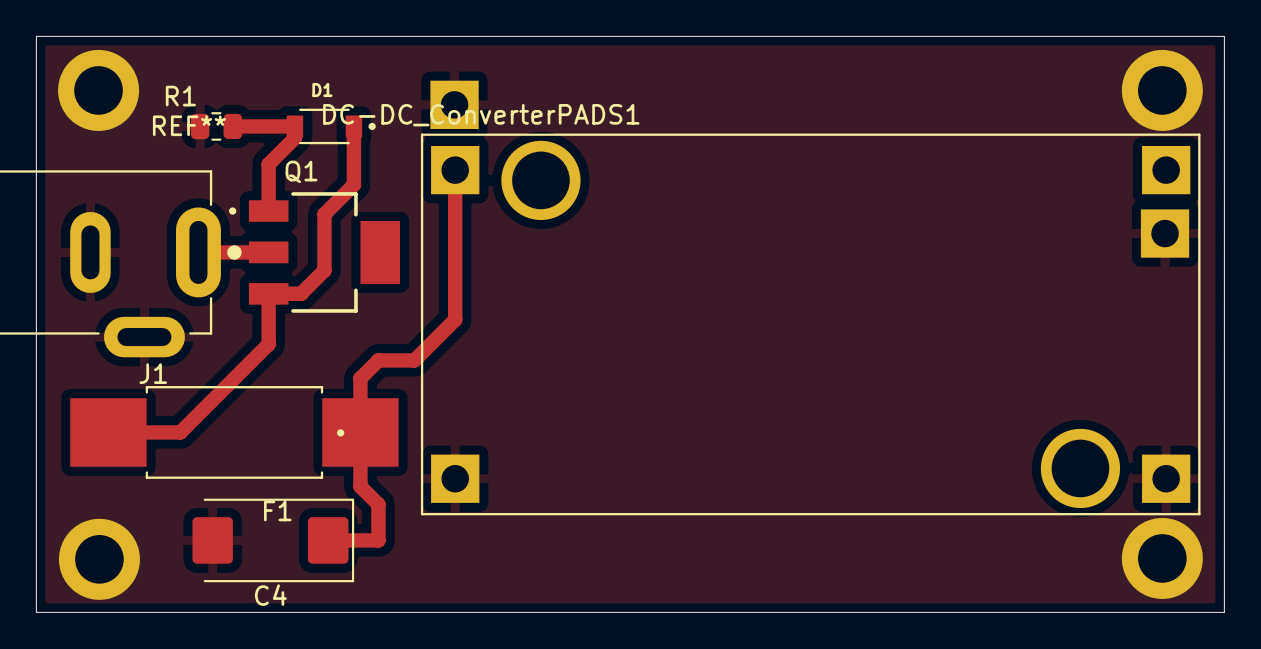
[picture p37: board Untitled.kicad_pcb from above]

Board: 2 copper layers, 66.0 x 32.0 mm, 7 parts (0 on the bottom side), 6 nets.

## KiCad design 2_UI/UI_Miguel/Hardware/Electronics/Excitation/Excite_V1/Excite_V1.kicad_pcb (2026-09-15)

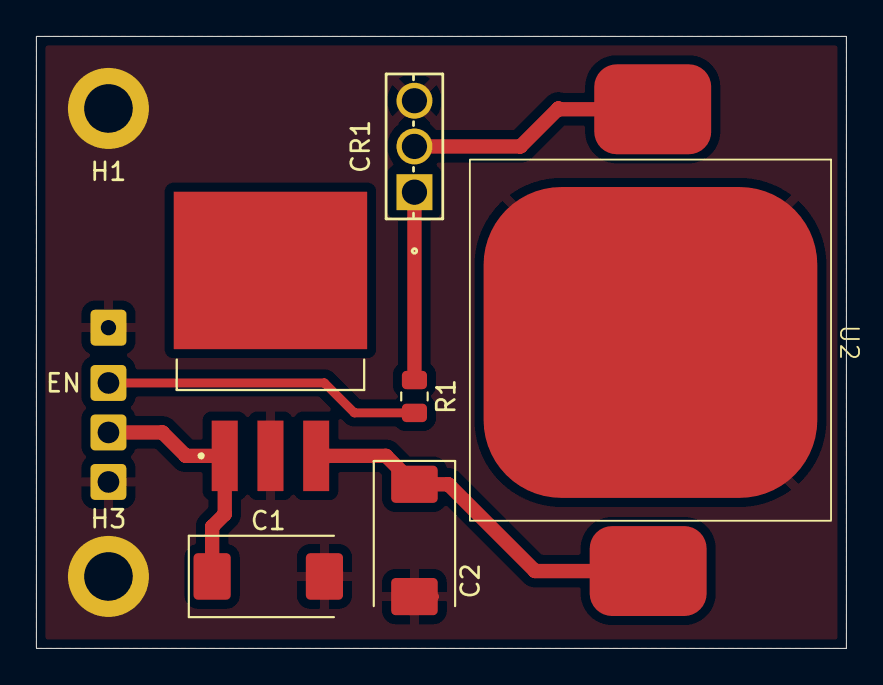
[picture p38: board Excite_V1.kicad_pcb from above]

Board: 2 copper layers, 45.0 x 34.0 mm, 9 parts (0 on the bottom side), 6 nets.

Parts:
C1, C2: 10uF; CP_EIA-7343-15_Kemet-W
CR1: BD681
EN: Enable_from_MC; SolderWire-0.25sqmm_1x01_D0.65mm_OD2mm
H1, H3: MountingHole_2.7mm_M2.5_ISO14580_Pad
R1: 10K; R_0805_2012Metric
U1: MIC29150-12WU-TR; MIC29150-12WU
U2: 10W_COB

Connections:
GND: C1.2, C2.2, CR1.3, H1.1, H3.3, U1.2 (GND), U2.3
unnamed: CR1.1, R1.2
unnamed: CR1.2, U2.1
unnamed: EN.1, R1.1
unnamed: C2.1, U1.3 (VOUT), U2.2
VDD: C1.1, U1.1 (VIN)

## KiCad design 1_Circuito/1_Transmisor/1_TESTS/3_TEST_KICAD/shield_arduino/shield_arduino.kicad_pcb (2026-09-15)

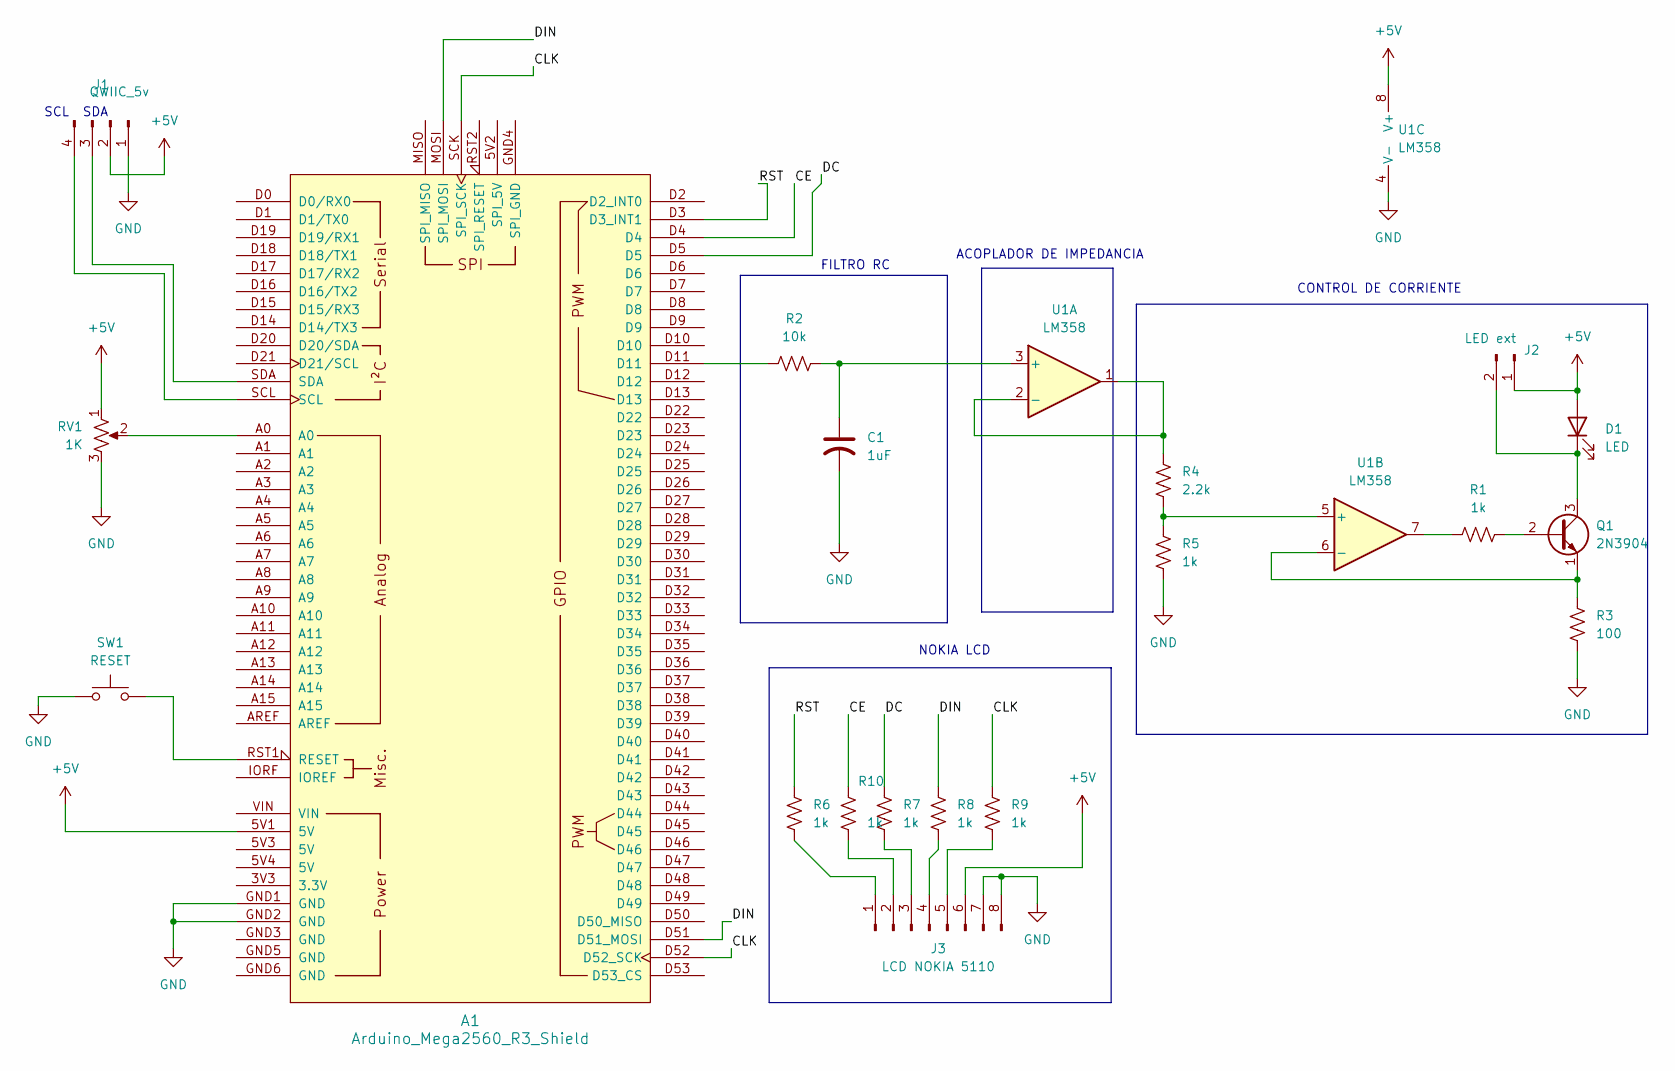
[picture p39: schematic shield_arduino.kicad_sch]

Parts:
A1: Arduino_Mega2560_R3_Shield
C1: 1uF; CP_Radial_D5.0mm_P2.50mm
D1: LED; LED_D3.0mm
J1: QWIIC_5v; PinHeader_1x04_P2.54mm_Vertical
J2: LED ext; PinHeader_1x02_P2.54mm_Vertical
J3: LCD NOKIA 5110; PinSocket_1x08_P2.54mm_Vertical
Q1: 2N3904; TO-92_Inline
R1, R5, R6, R7, R8, R9, R10: 1k; R_Axial_DIN0207_L6.3mm_D2.5mm_P10.16mm_Horizontal
R2: 10k; R_Axial_DIN0207_L6.3mm_D2.5mm_P10.16mm_Horizontal
R3: 100; R_Axial_DIN0207_L6.3mm_D2.5mm_P10.16mm_Horizontal
R4: 2.2k; R_Axial_DIN0207_L6.3mm_D2.5mm_P10.16mm_Horizontal
RV1: 1K; Potentiometer_Alps_RK163_Single_Horizontal
SW1: RESET; SW_PUSH_6mm_H5mm
U1: LM358; DIP-8_W7.62mm

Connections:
+5V: A1.5V1 (5V), D1.2 (A), J1.2, J2.1, J3.6, RV1.1, U1.8 (V+)
/CE: A1.D4, R10.1
/CLK: A1.D52 (D52_SCK), A1.SCK (SPI_SCK), R9.1
/DC: A1.D5, R7.1
/DIN: A1.D51 (D51_MOSI), A1.MOSI (SPI_MOSI), R8.1
/RST: A1.D3 (D3_INT1), R6.1
GND: A1.GND1 (GND), A1.GND2 (GND), C1.2, J1.1, J3.7, J3.8, R3.2, R5.2, RV1.3, SW1.1, U1.4 (V-)
unnamed: A1.A0, RV1.2
unnamed: A1.D11, R2.2
unnamed: A1.RST1 (RESET), SW1.2
unnamed: D1.1 (K), J2.2, Q1.3 (C)
unnamed: A1.SDA, J1.3
unnamed: A1.SCL, J1.4
unnamed: J3.1, R6.2
unnamed: J3.2, R10.2
unnamed: J3.3, R7.2
unnamed: J3.4, R8.2
unnamed: J3.5, R9.2
unnamed: Q1.2 (B), R1.1
unnamed: Q1.1 (E), R3.1, U1.6 (-)
unnamed: R1.2, U1.7
unnamed: C1.1, R2.1, U1.3 (+)
unnamed: R4.1, U1.1, U1.2 (-)
unnamed: R4.2, R5.1, U1.5 (+)

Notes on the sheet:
SCL SDA
NOKIA LCD
FILTRO RC
ACOPLADOR DE IMPEDANCIA
CONTROL DE CORRIENTE

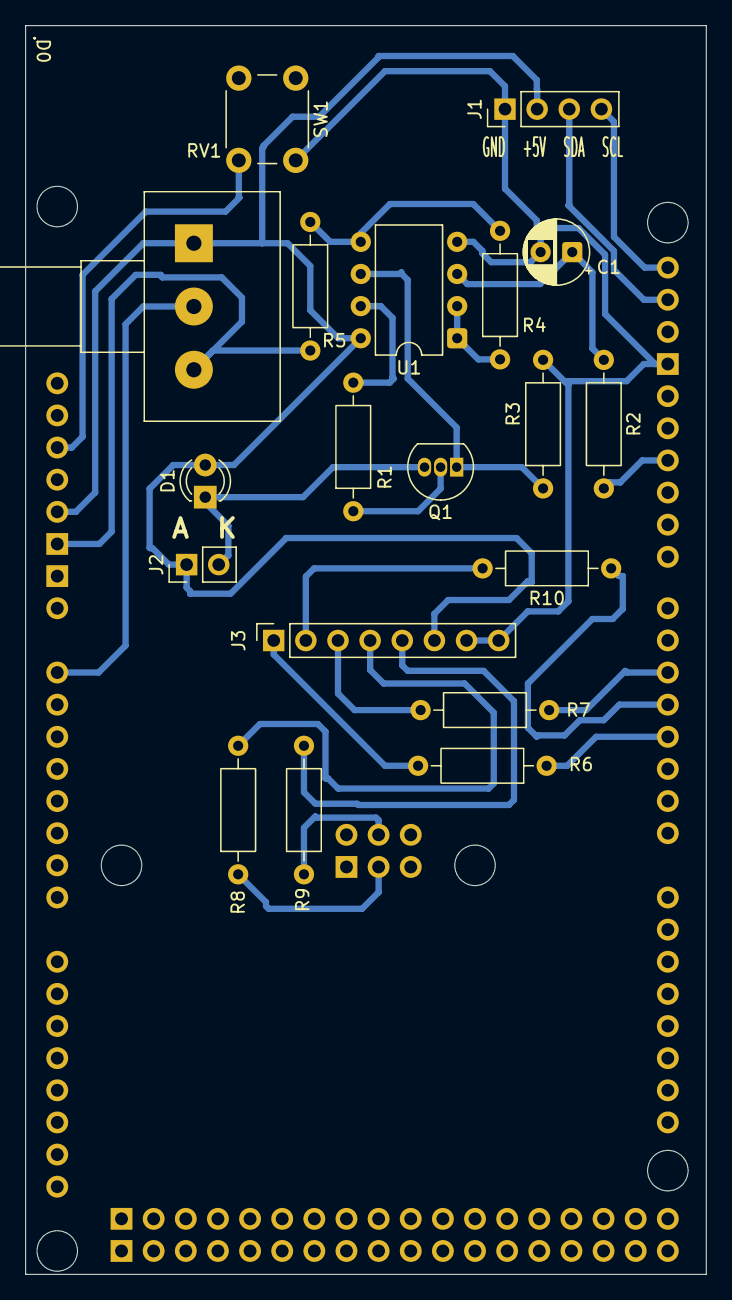
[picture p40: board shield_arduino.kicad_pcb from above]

Board: 2 copper layers, 53.8 x 98.7 mm, 20 parts (0 on the bottom side), 24 nets.

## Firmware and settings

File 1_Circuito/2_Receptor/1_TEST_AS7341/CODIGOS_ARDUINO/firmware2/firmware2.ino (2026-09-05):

#include <Wire.h>
#include <SPI.h>
#include <Adafruit_GFX.h>
#include <Adafruit_PCD8544.h>
#include <Adafruit_AS7341.h>

//================== CONFIGURACIÓN PANTALLA NOKIA 5110 ==================
const int pin_DC  = 5;
const int pin_CE  = 4;
const int pin_RST = 3;

// CONSTRUCTOR PARA HARDWARE SPI (Velocidad máxima de refresco)
Adafruit_PCD8544 display = Adafruit_PCD8544(pin_DC, pin_CE, pin_RST);

//================== CONFIGURACIÓN SENSOR AS7341 ==================
Adafruit_AS7341 as7341;

struct Canal {
  const char* nombre;
  uint16_t valor;
};

//================== CONFIGURACIÓN LED Y ADC ==================
const int pinDAC = 11;                // Pin 11 (Timer 1) para el LED en el Mega
const int pinPotenciometro = A0;      // Pin de lectura analógica para el potenciómetro
const int valorMaximoDigital = 1023;  // Resolución de 10 bits
const float voltajeMaximoArduino = 5.0;

// Variables de control de brillo
float voltajeExcitacion = 0.0;
int lecturaAnterior = 0;
const int umbralRuido = 5;            // Filtro para evitar que el ruido del potenciómetro haga oscilar el LED

void setup() {
  Serial.begin(115200);
  pinMode(pinDAC, OUTPUT);

  // Configuración del Timer 1 en el Arduino Mega (~15.6 kHz para evitar parpadeos)
  TCCR1A = _BV(COM1A1) | _BV(WGM11) | _BV(WGM10);
  TCCR1B = _BV(WGM12)  | _BV(CS10); 

  // Inicializar pantalla Nokia 5110
  display.begin();
  display.setContrast(55); 
  display.setRotation(2);  
  display.clearDisplay();
  display.display();

  // Inicializar sensor AS7341
  if (!as7341.begin()) {
    display.clearDisplay();
    display.setCursor(0,0);
    display.println("ERROR");
    display.println("AS7341");
    display.println("No detectado");
    display.display();
    while (1) { delay(10); }
  }

  // Configuración de integración rápida (~100ms) para respuesta en tiempo real
  as7341.setATIME(29);  
  as7341.setASTEP(599); 
  as7341.setGain(AS7341_GAIN_256X);

  Serial.println("Fluorímetro con Control de Brillo Continuo por ADC Listo.");
}

void loop() {
  // 1. Leer el potenciómetro y aplicar filtro de ruido
  int lecturaActual = analogRead(pinPotenciometro);
  
  if (abs(lecturaActual - lecturaAnterior) > umbralRuido) {
    lecturaAnterior = lecturaActual;
    // Mapeamos la lectura analógica de 0-1023 al voltaje de excitación deseado (0V a 5V)
    voltajeExcitacion = (lecturaActual * voltajeMaximoArduino) / 1023.0;
  }

  // 2. Ajustar el brillo del LED (Se queda encendido de forma continua, sin apagarse)
  fijarVoltajeDAC(voltajeExcitacion);

  // 3. Leer todos los canales del sensor espectral
  if (!as7341.readAllChannels()) {
    Serial.println("Error leyendo AS7341");
    return;
  }

  // 4. Procesar, ordenar y mostrar únicamente los 4 canales con mayor señal
  actualizarPantallaYProcesar();

  // Pequeña pausa para que el bucle fluya con suavidad y permita lecturas dinámicas
  delay(100); 
}

// Control analógico lineal mediante PWM por hardware
void fijarVoltajeDAC(float voltios) {
  if (voltios < 0.0) voltios = 0.0;
  if (voltios > voltajeMaximoArduino) voltios = voltajeMaximoArduino;
  int valorPWM = (voltios * valorMaximoDigital) / voltajeMaximoArduino;
  OCR1A = valorPWM; 
}

void actualizarPantallaYProcesar() {
  Canal canales[8] = {
    {"F1 415", as7341.getChannel(AS7341_CHANNEL_415nm_F1)},
    {"F2 445", as7341.getChannel(AS7341_CHANNEL_445nm_F2)},
    {"F3 480", as7341.getChannel(AS7341_CHANNEL_480nm_F3)},
    {"F4 515", as7341.getChannel(AS7341_CHANNEL_515nm_F4)},
    {"F5 555", as7341.getChannel(AS7341_CHANNEL_555nm_F5)},
    {"F6 590", as7341.getChannel(AS7341_CHANNEL_590nm_F6)},
    {"F7 630", as7341.getChannel(AS7341_CHANNEL_630nm_F7)},
    {"F8 680", as7341.getChannel(AS7341_CHANNEL_680nm_F8)}
  };

  // Imprimir espectro completo por Serial para monitoreo del sistema
  Serial.print("Vset: "); Serial.print(voltajeExcitacion); Serial.println(" V");
  Serial.println("--- Espectro de Emisión ---");
  for (int i = 0; i < 8; i++) {
    Serial.print(canales[i].nombre);
    Serial.print("nm: ");
    Serial.println(canales[i].valor);
  }
  Serial.println("");

  // Algoritmo de ordenamiento (Bubble Sort) de mayor a menor
  for (int i = 0; i < 7; i++) {
    for (int j = i + 1; j < 8; j++) {
      if (canales[j].valor > canales[i].valor) {
        Canal temp = canales[i];
        canales[i] = canales[j];
        canales[j] = temp;
      }
    }
  }

  // --- ACTUALIZAR PANTALLA NOKIA 5110 (Muestra estrictamente SOLO el Top 4) ---
  display.clearDisplay();
  display.setTextSize(1);
  display.setTextColor(BLACK);

  // Cabecera estática que muestra el Vset actual fijado por tu potenciómetro
  display.setCursor(0,0);
  display.print("Vset: ");
  display.print(voltajeExcitacion, 2);
  display.println("V");
  display.drawFastHLine(0, 8, 84, BLACK);

  // Imprimir los 4 canales con mayor señal en tiempo real
  for (int i = 0; i < 4; i++) {
    display.setCursor(0, 10 + i * 9);
    display.print(canales[i].nombre);
    display.print(":");

    display.setCursor(50, 10 + i * 9);
    
    uint16_t v = canales[i].valor;
    if (v >= 10000) {
      //display.print(v / 1000);
      //display.print("k");
      display.print(v);
    } else {
      display.print(v);
    }
  }

  display.display();
}

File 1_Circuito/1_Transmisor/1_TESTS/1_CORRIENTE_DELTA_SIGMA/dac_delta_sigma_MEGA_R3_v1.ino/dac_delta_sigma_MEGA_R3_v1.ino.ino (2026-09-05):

/*
  Fluorímetro de Bajo Costo: Control de Excitación (Pin 11) + Lectura Espectral (AS7341)
  Plataforma: Arduino Mega (ATmega2560)
*/

#include <Adafruit_AS7341.h>
#include <Wire.h>

Adafruit_AS7341 as7341;

// Configuración de la fuente de corriente constante (Timer 1 - Pin 11)
const int pinDAC = 11; 
const int valorMaximoDigital = 1023; // 10 bits de resolución
const float voltajeMaximoArduino = 5.0;

// Variables de calibración del ensayo
float voltajeExcitacion = 1.5; // Ajusta aquí el voltaje Vset analógico deseado (~4.68 mA en el LED)

void setup() {
  Serial.begin(115200);
  pinMode(pinDAC, OUTPUT);

  // --- CONFIGURACIÓN DE REGISTROS (Timer 1 en Arduino Mega) ---
  TCCR1A = _BV(COM1A1) | _BV(WGM11) | _BV(WGM10);
  TCCR1B = _BV(WGM12)  | _BV(CS10); // Fast PWM a ~15.6 kHz (sin parpadeos para el sensor)

  // Inicializar comunicación I2C y el sensor AS7341
  if (!as7341.begin()) {
    Serial.println("¡Error! No se pudo encontrar el sensor AS7341. Verifica el cableado I2C.");
    while (1) { delay(10); }
  }
  
  // Configurar parámetros ópticos del sensor para máxima precisión en laboratorio
  as7341.setATIME(100); // Tiempo de integración básico
  as7341.setASTEP(999); // Pasos de integración (Aumenta la sensibilidad frente a fluorescencia tenue)
  as7341.setGain(AS7341_GAIN_256X); // Ganancia alta (256x) ideal para captar emisiones débiles
  
  Serial.println("Sistema de Fluorometría Listo.");
}

void loop() {
  Serial.println("\n--- Iniciando Medición de Muestra ---");

  // 1. Encendemos el LED de excitación de forma analógica y continua (DC puro)
  fijarVoltajeDAC(voltajeExcitacion);
  Serial.print("LED encendido de forma estable. Vset = "); 
  Serial.print(voltajeExcitacion); 
  Serial.println(" V");
  
  delay(500); // Pausa corta para estabilización térmica del diodo antes de leer

  // 2. Realizamos la lectura de los canales espectrales del sensor
  if (!as7341.readAllChannels()){
    Serial.println("Error al leer los datos del sensor.");
    return;
  }

  // 3. Imprimimos los resultados en el monitor serial (enfocados en el espectro de emisión)
  Serial.println("[Lecturas de Fotones por Canal]");
  Serial.print("F1 (Violeta - 415nm): "); Serial.println(as7341.getChannel(AS7341_CHANNEL_415nm));
  Serial.print("F2 (Indigo  - 445nm): "); Serial.println(as7341.getChannel(AS7341_CHANNEL_445nm));
  Serial.print("F3 (Azul    - 480nm): "); Serial.println(as7341.getChannel(AS7341_CHANNEL_480nm));
  Serial.print("F4 (Cian    - 515nm): "); Serial.println(as7341.getChannel(AS7341_CHANNEL_515nm));
  Serial.print("F5 (Verde   - 555nm): "); Serial.println(as7341.getChannel(AS7341_CHANNEL_555nm));
  Serial.print("F6 (Amarillo- 590nm): "); Serial.println(as7341.getChannel(AS7341_CHANNEL_590nm));
  Serial.print("F7 (Naranja - 630nm): "); Serial.println(as7341.getChannel(AS7341_CHANNEL_630nm));
  Serial.print("F8 (Rojo    - 680nm): "); Serial.println(as7341.getChannel(AS7341_CHANNEL_680nm));

  // 4. Apagamos el LED de excitación entre muestras para evitar el fotoblanqueo (photobleaching)
  fijarVoltajeDAC(0.0);
  Serial.println("LED apagado. Esperando siguiente ciclo...");
  
  delay(5000); // Espera 5 segundos para la siguiente lectura de muestra
}

/*
  Control lineal del voltaje analógico para la fuente de corriente
*/
void fijarVoltajeDAC(float voltios) {
  if (voltios < 0.0) voltios = 0.0;
  if (voltios > voltajeMaximoArduino) voltios = voltajeMaximoArduino;
  int valorPWM = (voltios * valorMaximoDigital) / voltajeMaximoArduino;
  OCR1A = valorPWM; 
}

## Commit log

2026-07-07 Add initial files for DAC project including hex, Arduino sketch, simulation, and readme documentation
    - Added hex file for DAC implementation.
    - Created Arduino sketch for PWM DAC control.
    - Included simulation file for circuit testing.
    - Added readme files for project structure in various directories.
2026-07-08 Add DAC delta-sigma implementation for Arduino Mega and associated test files
    - Created a new Arduino sketch for high-speed PWM DAC (10 bits) using Timer 1 on Arduino Mega.
    - Added a simulation file for testing the delta-sigma DAC circuit.
    - Included images for the adapted circuit and original design for reference.
    - Added a video demonstrating LED control using the new DAC setup.
    - Updated README with circuit details, code explanation, and usage instructions.
2026-07-08 Add images and videos for LED current control tests and update README with simulation and implementation details
2026-07-08 Add images and update README for real circuit implementation and testing details
2026-07-10 Add lock files for KiCad PCB and schematic of Arduino shield
    - Created lock file for the PCB design: shield_arduino.kicad_pcb.lck
    - Created lock file for the schematic design: shield_arduino.kicad_sch.lck
    [Nokia LCD.igs, Nokia LCD.ipt, Nokia LCD.obj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]
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2026-07-10 Add LM358N component details and image to README for DAC LED UNO R4 tests
2026-07-10 Add lock files for KiCad PCB and schematic of Arduino shield
    - Created a lock file for the KiCad PCB: ~shield_arduino.kicad_pcb.lck
    - Created a lock file for the KiCad schematic: ~shield_arduino.kicad_sch.lck
    - Both files contain hostname and username information for the current user.
    [Nokia LCD.igs, Nokia LCD.ipt, Nokia LCD.obj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]
2026-07-10 Update README with circuit test descriptions and add 3D case design files
2026-07-13 Add new 3D case designs for Arduino Mega and update README
    [arduino_mega_top.stl, case_cubo-Fusion.stl]
2026-07-14 Add AS7341 sensor code examples and update README with detailed descriptions and images
2026-07-14 Add firmware examples for AS7341 sensor, update README with firmware details and images
2026-07-14 Add KiCad PCB design files for Arduino shield and remove obsolete lock file
2026-07-14 Update README with detailed project description, circuit structure, and 3D design information
2026-07-15 Add AS7341 sensor test code, update firmware pin configuration, and include new 3D case designs for Arduino Mega
2026-07-21 Add KiCad PCB design files for Arduino shield and remove lock files
2026-08-31 feat: add component 3D models and project documentation for shield-arduino circuit development
    [Nokia LCD.igs, Nokia LCD.ipt, Nokia LCD.obj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]
2026-08-31 feat: export KiCad PCB fabrication files and update characterization LED project documentation
    [shield_arduino-B_Cu.gbr, shield_arduino-B_Mask.gbr, shield_arduino-B_Silkscreen.gbr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]
2026-09-15 Refactor code structure for improved readability and maintainability
    [shield_arduino-B_Cu.dxf, shield_arduino-B_Cu_1.dxf, shield_arduino-Edge_Cuts.dxf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]
2026-09-15 fix: remove obsolete history directories for Arduino shield projects
    [Detector_V1.kicad_pcb, Detector_V1.kicad_sch, Energia .step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]
2026-09-15 Add LED Excitator schematic and project files
    - Created a new schematic file for the LED Excitator circuit, including components such as a connector and LED.
    - Added a new binary file for the project configuration.
    - Introduced a new binary file for additional project resources.
    [LED_EXCITATOR-B_Cu.gbr_iso_combined.DXF, LED_EXCITATOR-B_Cu.gbr_iso_combined_2.DXF, LED_EXCITATOR-B_Cu.gbr_iso_combined_3.DXF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]
2026-09-15 Add new 3D support structures for fluorimeter and microcentrifuge
    - Created `soporte_fluorimetro.FCStd` for fluorimeter support.
    - Added `soporte_micro_centrifuga.scad` for microcentrifuge tube holder with detailed dimensions and modular design.
    - Introduced `soporte_pcb.stl` for PCB support structure.
    - Developed `soporto_solo1.scad` for optical support of a fluorimeter, including features for AS7341 sensor and LED module.
    - Generated `soporto_solo1.stl` for the optical support structure.
    [caja_base.scad, cilindro1.scad, fluorimetro_soport2.scad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]
2026-09-15 feat: add additional telemetry data entries for improved analysis
    [telemetry.csv]
2026-09-15 feat: add additional telemetry data entries for enhanced tracking
    [telemetry.csv]
2026-09-15 feat: add experiment configuration JSON and extend telemetry data
    [telemetry.csv]
2026-09-16 Add new experiment data and telemetry logs for sessions on 2026-09-16
    - Created new experiment JSON files for sessions 20260916_151825_ae0542e7, 20260916_144511_800cb8e0, and 20260916_145935_276117e9, initializing with version 3 and empty capture results.
    - Added telemetry CSV files for sessions 20260916_144511_800cb8e0 and 20260916_145935_276117e9, containing detailed sensor readings and timestamps.
    [telemetry.csv]
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2026-09-21 Implement code changes to enhance functionality and improve performance
    [telemetry.csv]
